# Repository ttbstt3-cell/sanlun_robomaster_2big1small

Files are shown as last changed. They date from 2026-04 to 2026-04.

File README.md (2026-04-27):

# RoboMaster C板 SBUS 遥控车控制代码

基于 STM32F407IGHx 的 RoboMaster C板，使用 SBUS 协议接收遥控器信号，控制四个舵机（3个360度驱动轮 + 1个180度转向舵机）。

## 硬件配置

- **主控板**: RoboMaster C板 (STM32F407IGHx)
- **遥控器**: 乐迪遥控器 (SBUS信号)
- **舵机配置**:
  - 1号: 360度舵机 (大轮) - TIM1 CH1
  - 2号: 180度舵机 (转向) - TIM1 CH2
  - 3号: 360度舵机 (左小轮) - TIM1 CH3
  - 4号: 360度舵机 (右大轮) - TIM1 CH4

## 功能特点

### 1. 双模式控制

- **模式1 (驾驶模式)**: SwB 拨杆在下
  - 左摇杆上下 → 控制转向
  - 右摇杆上下 → 控制三个驱动轮前进/后退
  - 三个轮子按比例协同运动

- **模式2 (调试模式)**: SwB 拨杆在上
  - 右摇杆上下 → 单独控制1号大轮
  - 右摇杆左右 → 控制3号小轮或4号大轮
  - SwE 拨杆 → 切换控制3号或4号轮

### 2. 物理零点补偿 (TRIM)

解决360度舵机硬件公差问题：
- 现象：摇杆居中时轮子缓慢转动
- 解决：使用 TRIM_M1/M3/M4 补偿值
- 调整方法：
  - 轮子后退 → 增大TRIM值
  - 轮子前进 → 减小TRIM值

### 3. LED 状态指示

- 蓝灯 (PH10): 系统心跳，闪烁
- 绿灯 (PH12): SBUS信号正常时常亮
- 红灯 (PH11): 信号丢失时亮起

### 4. 失控保护

信号丢失时自动执行：
- 发送TRIM补偿值保持轮子静止
- 转向舵机锁定在中位

## 通道映射

| CH | 遥控器输入 | 功能 |
|----|---|---|
| CH1 | 右摇杆左右 | 调试模式控制小轮 |
| CH2 | 右摇杆上下 | 主驱动/油门 |
| CH3 | 左摇杆上下 | 转向控制 |
| CH5 | SwE | 选择3号/4号轮 |
| CH9 | SwB | 驾驶/调试模式切换 |

## SBUS 配置

- 波特率: 100000
- 数据位: 9位
- 停止位: 2位
- 校验: 偶校验 (EVEN)

## 文件结构

```
sanlun_robomaster/
├── Core/
│   ├── Inc/
│   │   ├── servo.h      # 舵机控制头文件
│   │   └── sbus.h       # SBUS协议头文件
│   └── Src/
│       ├── main.c       # 主程序
│       ├── servo.c      # 舵机控制实现
│       └── sbus.c      # SBUS解析实现
├── Drivers/             # STM32 HAL库
└── MDK-ARM/            # Keil工程文件
```

## 使用说明

1. 使用 Keil MDK 打开 `sanlun_robomaster.uvprojx` 工程
2. 编译并下载到 RoboMaster C板
3. 打开遥控器，确认 SBUS 信号正常
4. 根据需要调整 TRIM 值使轮子静止

## 调参步骤

1. 确保遥控器开机，SBUS信号正常（绿灯亮）
2. 不要触碰任何摇杆
3. 观察哪个轮子在转动
4. 修改 main.c 中的 TRIM 值：
   - `TRIM_M1` → 1号轮
   - `TRIM_M3` → 3号轮
   - `TRIM_M4` → 4号轮
5. 重新烧录，直到三个轮子都静止

## 更新日志

### 2026-04-27 最新更新

**Core/Src/main.c 主要修改：**

1. **TRIM 值调整**（解决舵机零点漂移）
   - 1号轮: 30 → -10
   - 3号轮: 30 → -20
   - 4号轮: 30 → -10

2. **通道映射变更**
   - CH10：模式切换（替代原 SwB/CH9）
   - CH6：单独控制1号轮
   - CH8：单独控制3号轮
   - CH9：单独控制4号轮
   - CH3：左摇杆上下控制转向
   - CH2：右摇杆上下控制轮子

3. **控制逻辑优化**
   - 添加摇杆死区处理（±50）
   - 改进速度计算和限幅
   - 优化双模式切换逻辑

### 历史版本

- **40ac3bb**：4号轮改为大轮
- **435b43f**：3号轮改小轮，1号和4号轮改大轮

## 许可证

MIT License

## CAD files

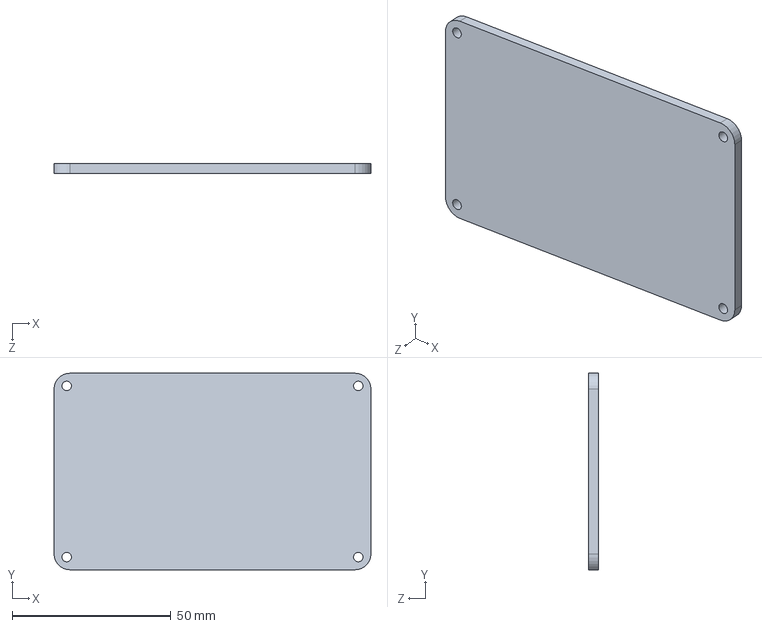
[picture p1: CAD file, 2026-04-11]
多轮式1/多轮1-外壳盖子1.SLDPRT
100.0 x 62.0 x 3.00 mm

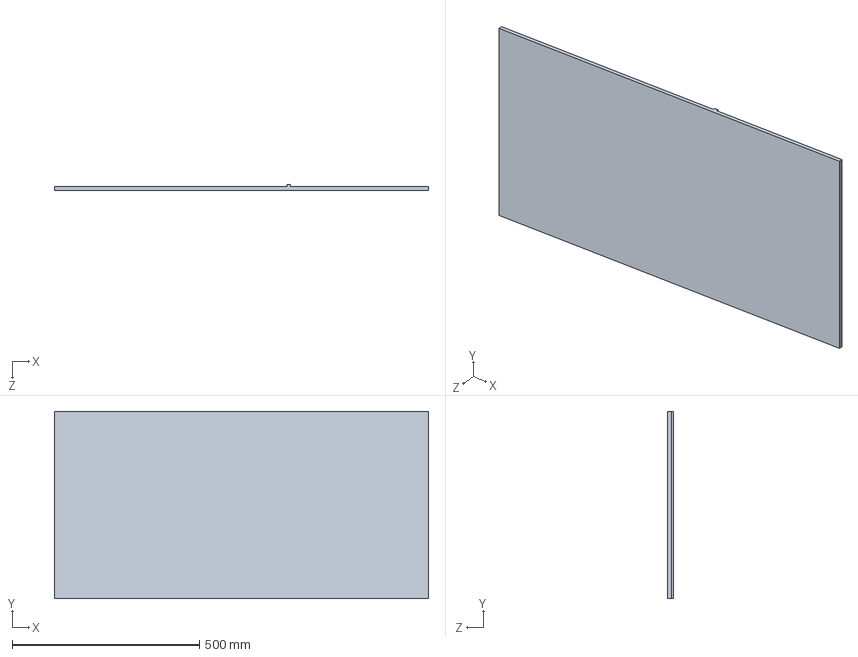
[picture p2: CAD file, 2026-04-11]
多轮式1/多轮1-底板1.SLDPRT
1000.0 x 500.0 x 15.0 mm

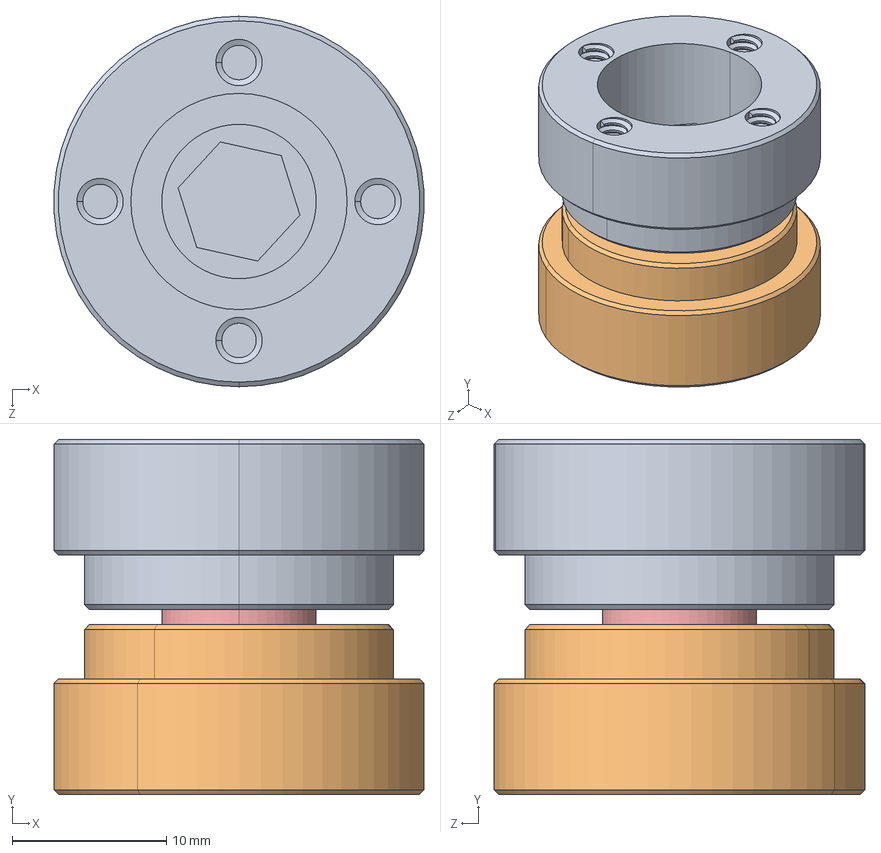
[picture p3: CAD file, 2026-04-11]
多轮式1/多轮1-DP1053-2.STEP
24.0 x 23.0 x 24.0 mm
錨璃1
錨璃2
M5蹟譫
錨璃3

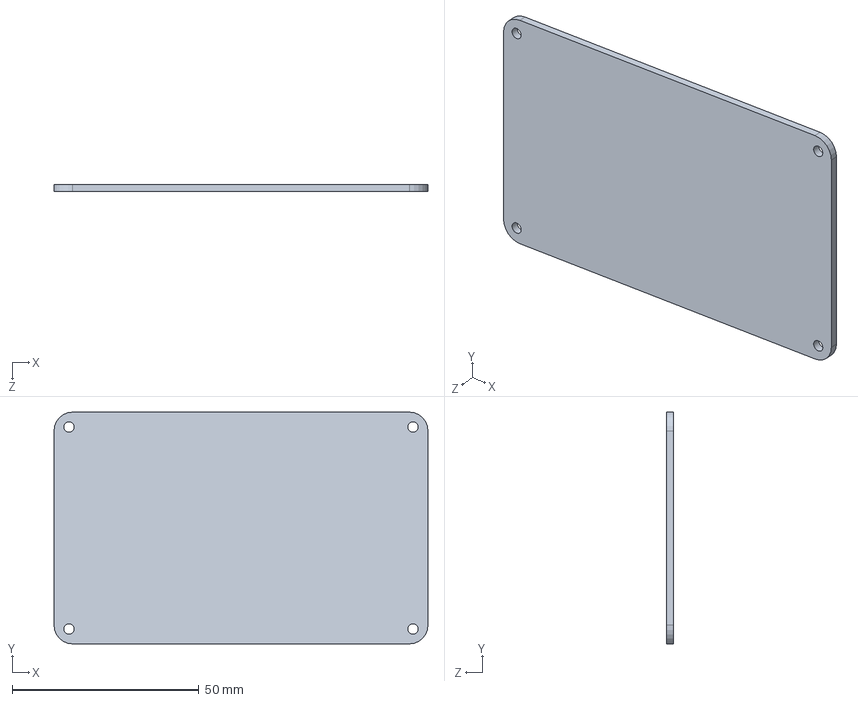
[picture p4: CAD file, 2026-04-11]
多轮式1/多轮1——盖子2.27.SLDPRT
100.0 x 62.0 x 2.00 mm

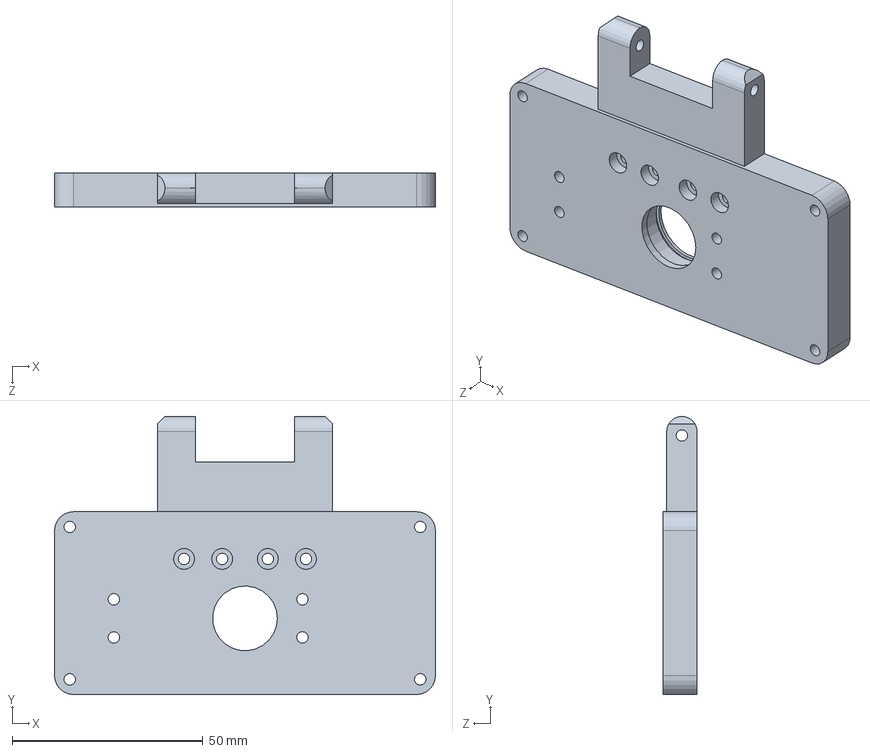
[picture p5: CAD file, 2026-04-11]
多轮式1/多轮1-转向_舵机支撑板_前.SLDPRT
100.0 x 73.0 x 9.00 mm

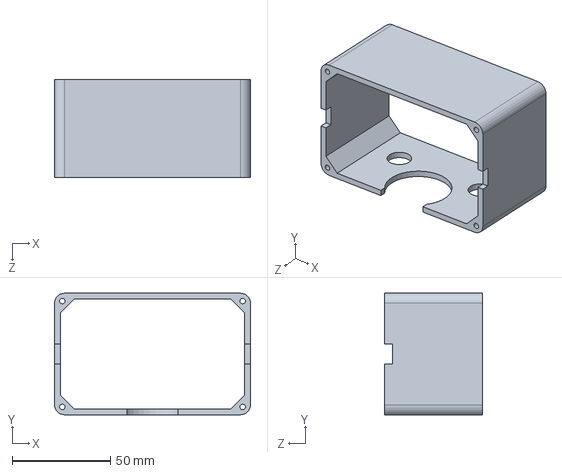
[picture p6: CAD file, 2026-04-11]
多轮式1/多轮1-外壳2.SLDPRT
100.0 x 62.0 x 50.0 mm

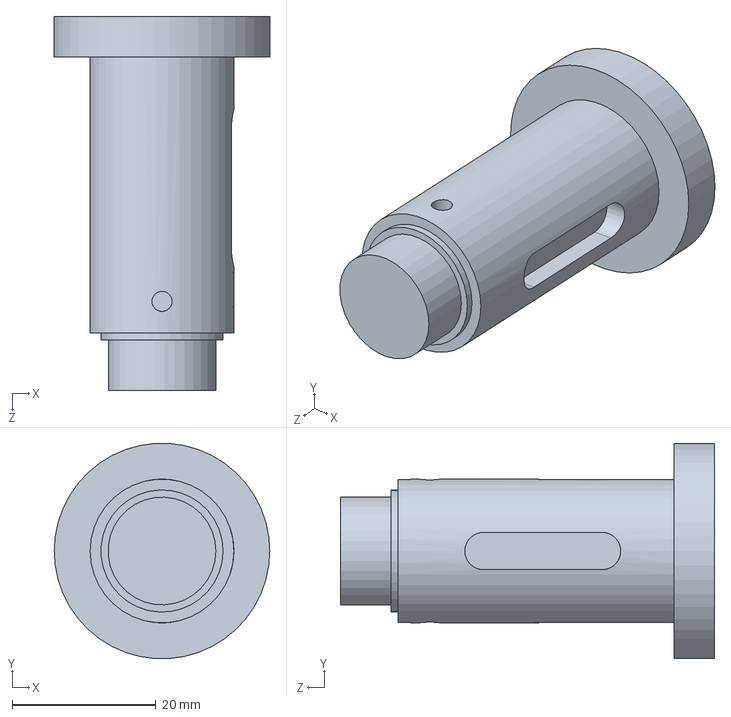
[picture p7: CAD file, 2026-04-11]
多轮式1/多轮1-大轮轴.SLDPRT
30.0 x 29.9 x 52.0 mm

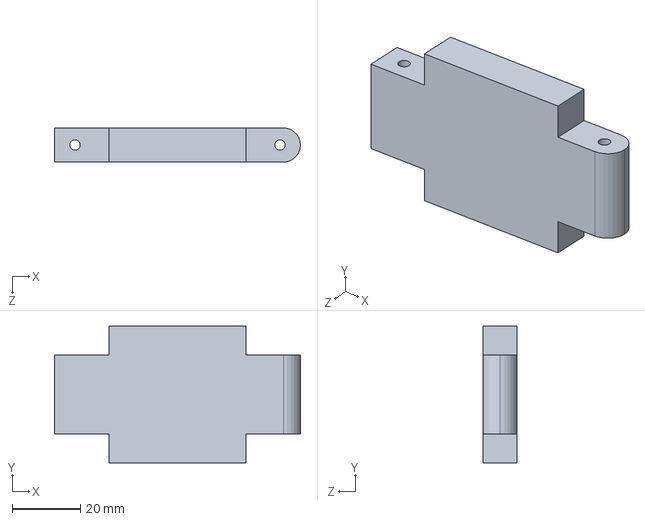
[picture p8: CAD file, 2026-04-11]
多轮式1/多轮1-连接板1.SLDPRT
72.0 x 40.0 x 10.0 mm

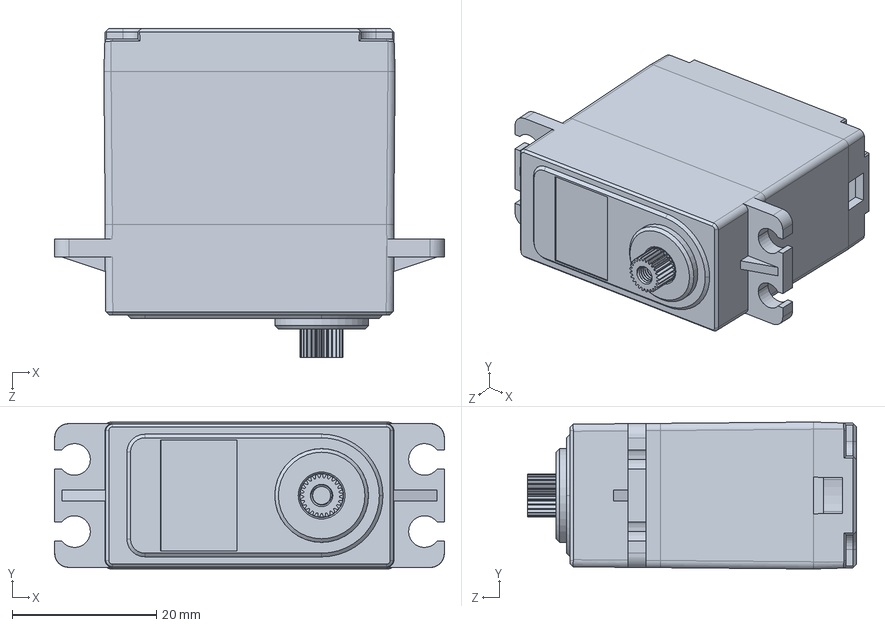
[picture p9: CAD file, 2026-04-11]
多轮式1/多轮1-驱动舵机.SLDPRT
54.1 x 20.4 x 45.7 mm

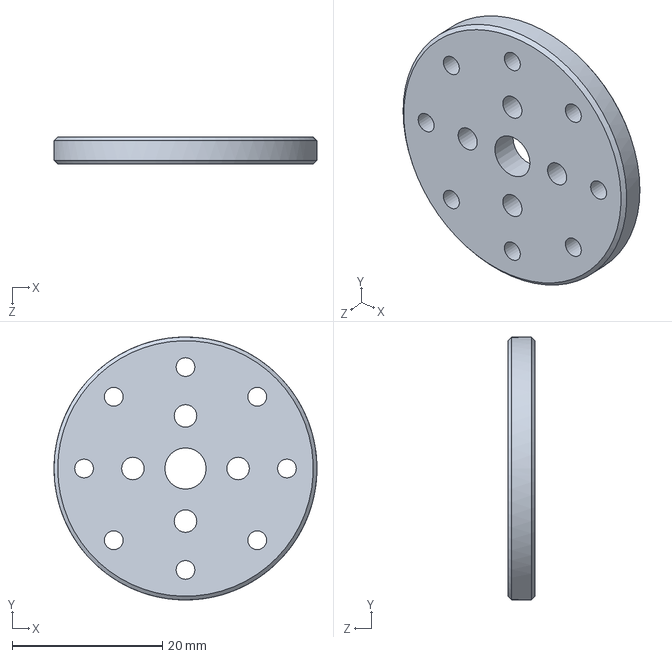
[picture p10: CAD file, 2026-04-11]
多轮式1/多轮1-驱动_舵机舵盘连接.SLDPRT
35.0 x 35.0 x 3.65 mm

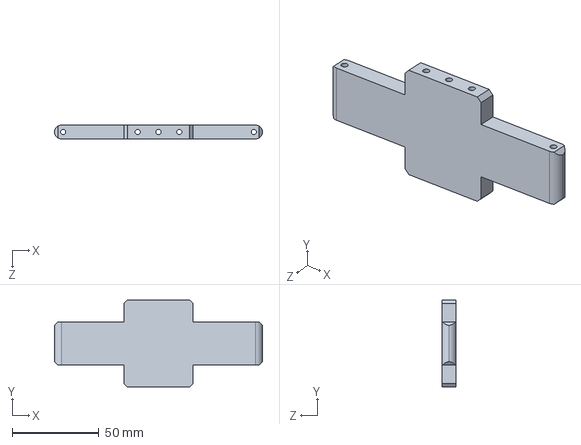
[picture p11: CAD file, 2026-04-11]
多轮式1/多轮1-大轮支撑轮连接板.SLDPRT
120.0 x 50.0 x 8.00 mm

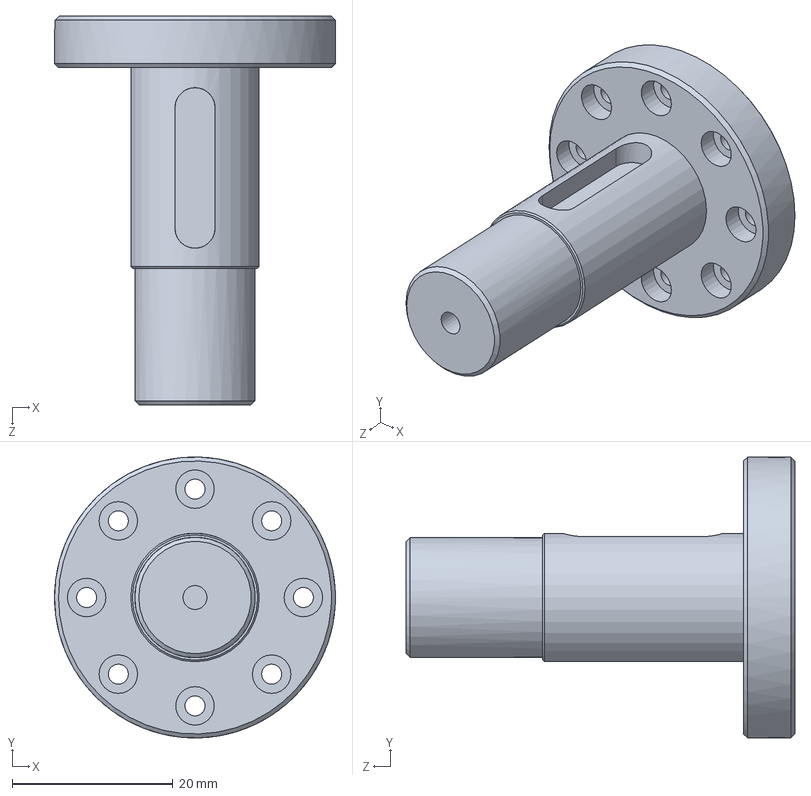
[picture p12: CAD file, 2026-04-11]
多轮式1/多轮1-驱动_轴.SLDPRT
35.0 x 35.0 x 48.4 mm

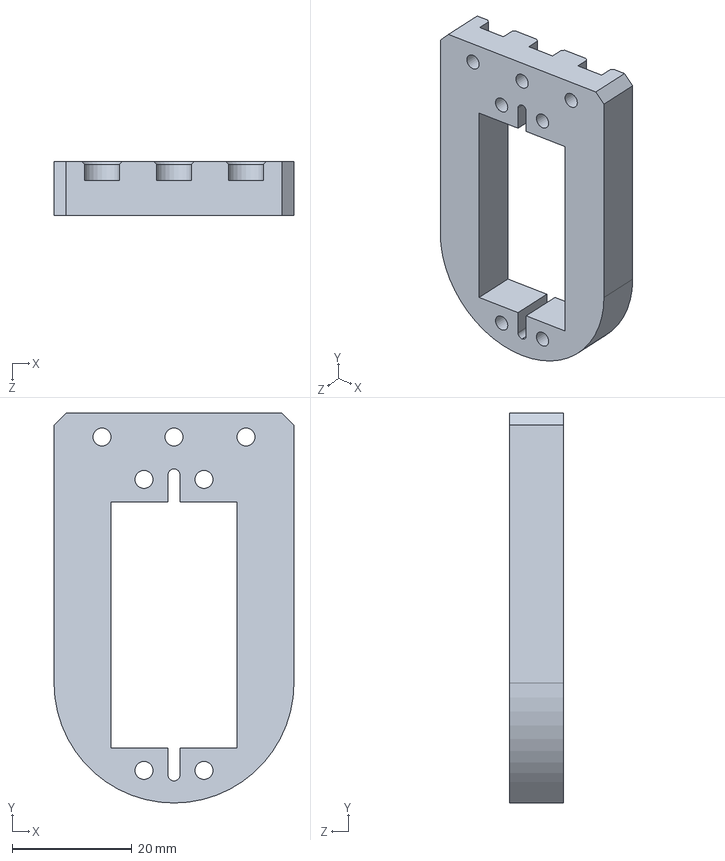
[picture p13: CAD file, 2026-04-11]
多轮式1/多轮1-驱动舵机支撑板.SLDPRT
40.0 x 65.0 x 9.00 mm

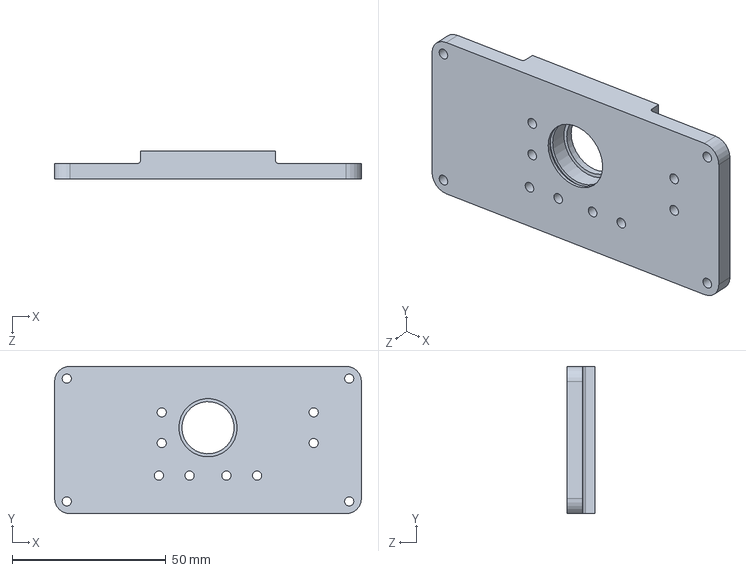
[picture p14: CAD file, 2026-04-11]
多轮式1/多轮1-转向_舵机支撑板_后.SLDPRT
100.0 x 48.0 x 9.00 mm

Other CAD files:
多轮式1/多轮1-DS3218.SLDASM
多轮式1/多轮1-DP053-2.SLDASM
多轮式1/多轮1-连接板左.SLDPRT
多轮式1/多轮1-驱动轴支撑板.SLDPRT
多轮式1/多轮-支撑轮连接板.SLDPRT
多轮式1/多轮1-25t金属舵盘.SLDPRT
多轮式1/多轮1-FZ1Z-W63.SLDPRT
多轮式1/多轮1-中间板.SLDPRT
多轮式1/多轮1-外壳1.SLDPRT
多轮式1/多轮1-外壳盖子2.SLDPRT
多轮式1/多轮1-大轮舵机支撑板.SLDPRT
多轮式1/多轮1-大轮驱动轴支撑板.SLDPRT
多轮式1/多轮1-支撑轮连接板.SLDPRT
多轮式1/多轮1-旋转铰链_固定座.SLDPRT
多轮式1/多轮1-相机.SLDPRT
多轮式1/多轮1-磁轮_W50.SLDPRT
多轮式1/多轮1-箱体2.SLDPRT
多轮式1/多轮1-转向舵机_法兰.SLDPRT
多轮式1/多轮1-连接件2.SLDPRT
多轮式1/多轮1-连接板.SLDPRT
多轮式1/多轮1-连接板右.SLDPRT
多轮式1/多轮1-驱动轴_套筒.SLDPRT
多轮式1/多轮1-驱动轴承_28.SLDPRT

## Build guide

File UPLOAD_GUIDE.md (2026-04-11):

# GitHub 上传步骤指南

## 准备工作

### 1. 安装 Git（如果尚未安装）
下载并安装 Git for Windows: https://git-scm.com/download/win

### 2. 配置 Git 用户信息
打开 Git Bash 或 PowerShell，执行以下命令：
```bash
git config --global user.email "your-email@example.com"
git config --global user.name "Your Name"
```

---

## 上传步骤

### 方法一：使用 Git 命令行

#### 步骤 1：打开项目目录
```bash
cd "C:\Users\ttbstt\Desktop\stm32\HAL\sanlun_robomaster"
```

#### 步骤 2：初始化 Git 仓库（如果尚未初始化）
```bash
git init
```

#### 步骤 3：配置远程仓库
```bash
git remote add origin https://github.com/ttbstt3-cell/SANLUN-ROBOMASTER.git
```

#### 步骤 4：添加文件到暂存区
```bash
git add .
```

#### 步骤 5：提交更改
```bash
git commit -m "Add RoboMaster C板 SBUS 遥控车控制代码及技术说明文档"
```

#### 步骤 6：推送到 GitHub
```bash
git push -u origin main
```

**注意**：如果仓库中已有内容，可能需要先 pull：
```bash
git pull origin main --allow-unrelated-histories
git push -u origin main
```

---

### 方法二：使用 GitHub Desktop

#### 步骤 1：下载并安装 GitHub Desktop
https://desktop.github.com/

#### 步骤 2：打开 GitHub Desktop 并登录

#### 步骤 3：添加本地仓库
- 点击 "File" → "Add Local Repository"
- 选择项目目录：`C:\Users\ttbstt\Desktop\stm32\HAL\sanlun_robomaster`

#### 步骤 4：填写提交信息
- 在左下角的 "Summary" 框中输入：`Add RoboMaster C板 SBUS 遥控车控制代码及技术说明文档`

#### 步骤 5：点击 "Commit to main"

#### 步骤 6：点击 "Push origin" 推送到 GitHub

---

### 方法三：使用 VS Code（推荐）

#### 步骤 1：在 VS Code 中打开项目目录

#### 步骤 2：点击左侧的 Git 图标

#### 步骤 3：点击 "初始化仓库"（如果是第一次）

#### 步骤 4：在 "更改" 区域点击 "+" 暂存所有更改

#### 步骤 5：在上方的输入框中输入提交信息

#### 步骤 6：点击 "✓" 提交

#### 步骤 7：点击 "同步更改" 推送到 GitHub
- 首次同步时会提示登录 GitHub

---

## 文件说明

本次上传包含以下文件：

| 文件 | 说明 |
|---|---|
| `Core/Src/main.c` | 主程序，包含双模式控制逻辑 |
| `Core/Src/servo.c` | 舵机 PWM 控制实现 |
| `Core/Src/sbus.c` | SBUS 协议解析实现 |
| `Core/Inc/servo.h` | 舵机控制头文件 |
| `Core/Inc/sbus.h` | SBUS 协议头文件 |
| `README.md` | 快速入门指南 |
| `DOCUMENTATION.md` | **技术说明文档（新增）** |

---

## 常见问题

### Q: 推送时提示需要登录
**A**: 在弹出的窗口中登录您的 GitHub 账户

### Q: 提示 "refusing to merge unrelated histories"
**A**: 执行以下命令：
```bash
git pull origin main --allow-unrelated-histories
```

### Q: 推送被拒绝 "denied to username"
**A**: 检查是否有仓库的推送权限，或者使用个人访问令牌（Personal Access Token）

### Q: 网络连接失败
**A**: 
- 检查网络连接
- 如果使用代理，配置 Git 代理：
```bash
git config --global http.proxy http://proxy.example.com:8080
git config --global https.proxy https://proxy.example.com:8080
```

---

## 上传完成后

1. 访问 https://github.com/ttbstt3-cell/SANLUN-ROBOMASTER 确认文件已上传
2. 确认 `DOCUMENTATION.md` 已包含在仓库中

---

如有任何问题，请随时询问！

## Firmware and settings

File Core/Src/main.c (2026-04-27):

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
/* Includes ------------------------------------------------------------------*/
#include "main.h"

/* USER CODE BEGIN Includes */
#include "sbus.h"
#include "servo.h"
/* USER CODE END Includes */

TIM_HandleTypeDef htim1;
TIM_HandleTypeDef htim8;

UART_HandleTypeDef huart1;
UART_HandleTypeDef huart3;
DMA_HandleTypeDef hdma_usart3_rx;

void SystemClock_Config(void);
static void MX_GPIO_Init(void);
static void MX_DMA_Init(void);
static void MX_TIM1_Init(void);
static void MX_TIM8_Init(void);
static void MX_USART1_UART_Init(void);
static void MX_USART3_UART_Init(void);
/**
  * @brief  The application entry point.
  * @retval int
  */
int main(void)
{

  /* MCU Configuration--------------------------------------------------------*/

  /* Reset of all peripherals, Initializes the Flash interface and the Systick. */
  HAL_Init();

  /* Configure the system clock */
  SystemClock_Config();

  /* Initialize all configured peripherals */
  MX_GPIO_Init();
  MX_DMA_Init();
  MX_TIM1_Init();
  MX_TIM8_Init();
  MX_USART1_UART_Init();
  MX_USART3_UART_Init();
  /* USER CODE BEGIN 2 */
  // 初始化SBUS和舵机
  SBUS_Init();
  Servo_Init();


  
  // LED闪烁计数器
  uint32_t led_tick = 0;

  /* USER CODE END 2 */

  // =========================================================
  // 🛠️ 【终极调车环节：寻找三颗"魔法数字"】 🛠️
  // 现象：摇杆不碰时，某个轮子还在轻微转动。
  // 规律：
  // - 如果轮子缓慢【后退】，说明补偿不够，把数字【改大】（比如从20改成 30, 40, 50...）
  // - 如果轮子缓慢【前进】，说明补偿过头，把数字【改小】（比如从20改成 10, 0, 甚至 -10, -20...）
  // 请反复修改下面三个数字并烧录，直到开机后三个轮子绝对静止！
  // =========================================================
  #define TRIM_M1  -10  // 👈 1号大轮的专属补偿值 (请根据实际情况改动)
  #define TRIM_M3  -20  // 👈 3号小轮的专属补偿值
  #define TRIM_M4  -10  // 👈 4号大轮的专属补偿值

  /* Infinite loop */
  /* USER CODE BEGIN WHILE */
  while (1)
  {
    // ====== LED 状态指示 ======
    led_tick++;
    if(led_tick >= 50)  
    {
      led_tick = 0;
      HAL_GPIO_TogglePin(GPIOH, GPIO_PIN_10);  // 蓝灯闪烁 (系统心跳)
    }
    
    // 信号状态灯
    if(SBUS_IsValid()) {
      HAL_GPIO_WritePin(GPIOH, GPIO_PIN_12, GPIO_PIN_RESET);  // 绿灯常亮
      HAL_GPIO_WritePin(GPIOH, GPIO_PIN_11, GPIO_PIN_SET);    // 红灯灭
    } else {
      HAL_GPIO_WritePin(GPIOH, GPIO_PIN_12, GPIO_PIN_SET);    // 绿灯灭
      HAL_GPIO_WritePin(GPIOH, GPIO_PIN_11, GPIO_PIN_RESET);  // 红灯亮 
    }
    
    SBUS_Process();

    // ====== 双模式控制 ======
    if (SBUS_IsValid())
    {
        int16_t channel2 = SBUS_GetChannel(2);  // 【右摇杆 上下】 控制轮子

        int16_t channel10 = SBUS_GetChannel(10); // 【CH10】 模式切换
        int16_t channel6 = SBUS_GetChannel(6);   // 【CH6】 单独控制1号轮
        int16_t channel8 = SBUS_GetChannel(8);   // 【CH8】 单独控制3号轮
        int16_t channel9 = SBUS_GetChannel(9);   // 【CH9】 单独控制4号轮
        int16_t channel3 = SBUS_GetChannel(3);   // 【左摇杆 上下】 控制转向

        int16_t servo1_speed = 0;
        int16_t servo3_speed = 0;
        int16_t servo4_speed = 0;

        // 计算右摇杆上下速度
        int16_t ch2_offset = channel2 - 1024;
        int16_t ch2_speed = 0;
        if (ch2_offset > -50 && ch2_offset < 50) {
            ch2_speed = 0;  // 死区
        } else if (ch2_offset >= 50) {
            ch2_speed = (ch2_offset * 1000) / (1700 - 1024);
        } else {
            ch2_speed = (ch2_offset * 1000) / (1024 - 300);
        }

        // 限幅
        if (ch2_speed > 1000) ch2_speed = 1000;
        if (ch2_speed < -1000) ch2_speed = -1000;

        if (channel10 >= 1000)
        {
            // ====== 同步模式：CH10开启，三个轮子一起动 + 转向 ======
            servo1_speed = -(ch2_speed * 50) / 63;  // 1号大轮
            servo3_speed = -ch2_speed;             // 3号小轮
            servo4_speed = -(ch2_speed * 50) / 63; // 4号大轮

            // CH3控制转向舵机（方向取反）
            int16_t ch3_offset = channel3 - 1024;
            uint16_t steer_pulse = 1500;
            if (ch3_offset > -30 && ch3_offset < 30) {
                steer_pulse = 1500;  // 死区：中位
            } else if (ch3_offset >= 30) {
                steer_pulse = 1500 - (ch3_offset * 1000) / (1700 - 1024);
            } else {
                steer_pulse = 1500 - (ch3_offset * 1000) / (1024 - 300);
            }
            if (steer_pulse < 500) steer_pulse = 500;
            if (steer_pulse > 2500) steer_pulse = 2500;
            Servo_Set180(2, steer_pulse);
        }
        else
        {
            // ====== 独立模式：CH6/CH8/CH9分别控制各轮 ======
            // CH6拨杆控制1号轮（大轮，需50/63换算，方向取反）
            if (channel6 >= 1000) {
                servo1_speed = -(ch2_speed * 50) / 63;
            }

            // CH8拨杆控制3号轮（小轮，直接输出，方向取反）
            if (channel8 >= 1000) {
                servo3_speed = -ch2_speed;
            }

            // CH9拨杆控制4号轮（大轮，需50/63换算，方向取反）
            if (channel9 >= 1000) {
                servo4_speed = -(ch2_speed * 50) / 63;
            }

            // 独立模式时转向舵机锁定中位
            Servo_Set180(2, 1500);
        }

        // 下发速度指令 (带着物理微调补偿)
        Servo_Set360(1, servo1_speed + TRIM_M1);
        Servo_Set360(3, servo3_speed + TRIM_M3);
        Servo_Set360(4, servo4_speed + TRIM_M4);
    }
    else
    {
        // ====== 完美的断电失控保护 =====
        // ！！！失控时绝对不能发 0，必须发微调补偿值，否则关控后车依然会倒退 !!!
        Servo_Set360(1, TRIM_M1);
        Servo_Set360(3, TRIM_M3);
        Servo_Set360(4, TRIM_M4);
        Servo_Set180(2, 1500);  // 失控时转向锁定中位
    }
    
    HAL_Delay(10);
  }
  /* USER CODE END WHILE */
}

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


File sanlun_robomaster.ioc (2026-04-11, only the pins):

Mcu.UserName=STM32F407IGHx
PA10.Signal=S_TIM1_CH3
PA11.Signal=S_TIM1_CH4
PA13.Signal=SYS_JTMS-SWDIO
PA14.Signal=SYS_JTCK-SWCLK
PA8.Signal=S_TIM1_CH1
PA9.Signal=S_TIM1_CH2
PB6.Signal=USART1_TX
PB7.Signal=USART1_RX
PC10.Signal=USART3_TX
PC11.Signal=USART3_RX
PH0-OSC_IN.Signal=RCC_OSC_IN
PH1-OSC_OUT.Signal=RCC_OSC_OUT
PH10.Signal=GPIO_Output
PH11.Signal=GPIO_Output
PH12.Signal=GPIO_Output
PI2.Signal=S_TIM8_CH4
PI5.Signal=S_TIM8_CH1
PI6.Signal=S_TIM8_CH2
PI7.Signal=S_TIM8_CH3

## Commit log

2026-04-11 修改轮子配置：3号轮改小轮，1号和4号轮改大轮
    [多轮-支撑轮连接板.SLDPRT, 多轮1-25t金属舵盘.SLDPRT, 多轮1-DP053-2.SLDASM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]
2026-04-11 更新README：4号轮改为大轮
2026-04-27 更新README：添加最新更改记录

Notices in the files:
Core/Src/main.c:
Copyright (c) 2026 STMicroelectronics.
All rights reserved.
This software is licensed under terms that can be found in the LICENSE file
